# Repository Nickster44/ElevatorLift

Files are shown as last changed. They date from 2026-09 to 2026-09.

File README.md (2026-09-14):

# Elevator Lift Controller Redesign

This repository contains the Rev-A hardware design and inhibited software for a redesigned outdoor elevator lift controller. The original controller was a Particle Xenon sketch that drove an EM01 VFD over serial, watched a safety loop, counted position pulses in firmware, stored floor positions in EEPROM, and exchanged simple serial messages with a secondary relay/input board.

The new design goals are:

- Make motion control deterministic and auditable with an explicit state machine.
- Move encoder counting out of interrupt-heavy application code and into a quadrature counter IC.
- Store current position, floor targets, calibration values, faults, and event logs in nonvolatile MRAM.
- Host a local access-point web interface for setup, diagnostics, data logs, and maintenance actions, with optional station-mode connection to a local network.
- Keep safety functions electrically independent from the MCU wherever possible.
- Develop the custom controller board alongside a versioned firmware interface contract.

Important: this repository is not a certified elevator controller. The software here is a development baseline. Any real lift must use appropriately rated safety devices, hardwired interlocks, braking/enable circuits, limit switches, emergency stop hardware, enclosure design, and professional review before operation.

## Software Integration Status (2026-09-13)

The active software is a **buildable but hardware-inhibited N16R8 profile**.
GPIO35-37 are unavailable on this module. The 2026-09-13 hardware update moves
LIMIT_UP/LIMIT_DOWN/SERVICE_KEY to GPIO43/44/3 and makes GPIO42 a communications-only
UART enable, removing the MCU RUN and optional AUX circuits. Software contract v2
now adopts this revision. GPIO3 is input-only, UART0 application logging is disabled,
and UART1 supports STOP/monitor/readback while safety is open. RUN, drive writes,
motion and uploads remain inhibited. Stable input levels do not prove wire continuity.
No physical motion or hardware verification has been performed.

VFD communication now includes periodic STOP refresh (300 ms scheduled interval),
monitor/read traffic, and a separate bounded reply-retry policy. The drive's TIME
watchdog is read and reported, never automatically changed; communication failure
keeps STOP refresh active without restarting motion or clearing faults.

The manual-release STOP path is now target-bound: key/hold/direction release or
invalid direction/safety input queues STOP before ordinary work. Input intent is
reported separately from actual motion permission. The requested operational v3
profile, RF programming and calibration expansion are not complete; v2 remains inhibited.

See the [hardware change and routing handoff](docs/reviews/2026-09-13-pin-comms-fourlayer.md).
The PCB is synchronized and has four copper layers, but remains unrouted and
not layout-release/fabrication ready; isolation keepouts and fabricator-specific
stackup/USB geometry still need completion.

Start with the [software integration checklist](docs/software-integration-checklist.md),
[hardware-dependency handoff](docs/hardware-dependency-handoff.md),
[firmware guide](firmware/README.md) and [current API contract](webapp/docs/api-contract.md).
Portable motion/protocol/device logic has regression tests; target commissioning,
RF integration and several guarded API workflows remain incomplete. The WebUI
shows unavailable capabilities instead of simulating successful hardware actions.

## Current Repository Layout

Use the [documentation guide](docs/README.md) to distinguish current design
guidance from dated reviews and historical evidence.

```text
_old_resources/
  old_code.ino.txt                 Original Particle Xenon firmware
  EM01 Manual User_EN-V1.02.pdf     VFD manual; serial protocol starts on page 27
  SKF-Motor-Encoder-Unit---15276_1-EN.pdf
docs/
  hardware-requirements-matrix.md   Schematic-facing hardware requirements
  hardware-selection.md             Selected Rev-A hardware
  home-automation-integration.md    Local REST/Home Assistant/Google Home bridge plan
  jlcpcb-lcsc-sourcing.md           JLCPCB/LCSC-oriented major part matrix
  motion-control-and-calibration.md Motion strategy and measured stop calibration
  old-system-review.md              Existing firmware/hardware behavior and risks
  vfd-serial-protocol.md            Extracted EM01 serial protocol notes
  new-controller-requirements.md    Hardware and firmware requirements draft
  webui-vfd-and-storage-plan.md     WebUI, VFD parameter, and log storage plan
  webapp-embedded-delivery.md       ESP32 static bundle budget and serving rules
  field-verification-log.md         Observed legacy hardware and remaining site checks
  schematic-capture-readiness.md    Rev-A capture inputs, BOM register, and release gates
datasheets/
  README.md                         Local datasheet manifest for major ICs/modules
firmware/
  platformio.ini                    Inhibited N16R8 PlatformIO target
  include/
  src/
webapp/
  app/                              Full development and service-console UI
  embedded/                         Static entry point for the ESP32 build
  docs/                             WebUI API, safety, and delivery contracts
hardware/
  ElevatorLift.kicad_pro            KiCad 10 project; open this file
  ElevatorLift.kicad_sch            Root hierarchical schematic
  Power_RevA.kicad_sch              AC input and 12 V/5 V/3.3 V power
  MCU_Storage_RevA.kicad_sch        ESP32-S3, USB, MRAM and RTC
  VFD_Interface_RevA.kicad_sch      VFD UART and communications-only OE
  Encoder_Counter_RevA.kicad_sch    Encoder isolation and counter
  IO.kicad_sch                      RF, field inputs and outputs
  ElevatorLift.kicad_pcb            PCB WIP; full footprint/net transfer on a 90 mm x 90 mm outline with 86 mm hole centers
  ElevatorLift_Custom.kicad_sym     Project-owned symbols
  ElevatorLift_Custom.pretty/       Project-owned footprints
  SnapEDA-Library/                  Vendored imported symbols, footprints and STEP files
  sym-lib-table / fp-lib-table      Portable project library registrations
  architecture-blocks.md            Block-level hardware architecture notes
```

## Current Design Knowledge

The current hardware direction is an `ESP32-S3-WROOM-1U-N16R8` controller board in the VFD enclosure, using a self-hosted Wi-Fi AP as the primary service path and optional station Wi-Fi for local-network access. Ethernet is not a near-term requirement.

Known design constraints captured so far:

- KiCad 10.0.4 is the active hardware design version.
- Measured legacy mechanical target is approximately 90 mm x 90 mm with corner mounting-hole centers 86 mm apart; 2.56 mm hole diameter remains to be confirmed.
- The Rev-A VFD serial circuit has been cross-checked against the field design and reproduces its TI `TXS0104E` 3.3 V-to-5 V topology. The assembled board, connector pinout, reference, and idle levels still require bench verification before lift connection.
- The observed encoder path appears to be 12 V open-collector A/B with 270 ohm pullups and 270 ohm series resistors feeding a `TLP291-4` optocoupler. Trace details, current, and maximum pulse rate remain open.
- Legacy Linx/TE RXM-418-LR 418 MHz RF remote support is mandatory.
- Baseline control supply is RECOM `RAC10-12SK/277`, 12 V, 10 W, based on the previously observed installation; `C5199922` is a recorded sourcing reference, not verified current availability.
- Rev A retains a jumper-selectable external 12 V lighting input. Use it if measured controller margin is insufficient or future lighting requires more power than the onboard supply can provide.
- Critical state and recent logs should use 4 Mbit SPI/QPI MRAM, using the selected Siproin `PM004MNIATR`.
- Web assets, OTA staging and noncritical logs should use the module's 16 MB flash and 8 MB PSRAM first. Rev A does not include a separate QSPI NOR device.
- Outside control should use local REST first, optional MQTT later, and Home Assistant as the recommended bridge to Google Home, watches, and broader automation.
- Motion control should use measured deceleration-distance stopping, not PID. Planned calibration starts explicitly after valid floor programming and stores direction-specific offsets; target integration remains incomplete.

## Legacy Reference

The original pin map, behavior and risk analysis are retained in
[old-system-review.md](docs/old-system-review.md). They are historical evidence,
not wiring or operating instructions for Rev A.

## Firmware Direction

The firmware targets the exact N16R8 module using Arduino/PlatformIO and a versioned hardware interface contract. Portable core logic is tested separately from target adapters. A successful build is not permission to deploy.

Key modules:

- `core/Supervisor`: fault-latched motion, service, homing and measured calibration logic.
- `core/Em01`, `DriveScheduler`: framed/checksummed transactions, telemetry and readback.
- `core/Devices`, `Configuration`: LS7366R, PM004 MRAM, RTC and integrity-checked records.
- `core/Rf`: isolated learned-slot/epoch and input arbitration logic.
- `main.cpp`: inhibited target diagnostics, light output, networking and static hosting.
- `interface-contract.json`: confirmed pins and explicit unresolved hardware decisions.

## Local Web Interface/API

The firmware hosts static WebUI assets on port 80 and a fallback AP. Station credentials can be saved, but remote reboot is deliberately unsupported in the inhibited profile. Failed/lost station connectivity restores AP access. Blank API tokens disable writes.

Endpoints:

- `GET /` - embedded WebUI; no automatic demo mode.
- `GET /api/status` - versioned status, capabilities, blocked reasons and freshness.
- `GET /api/capabilities` - explicit supported capabilities.
- `GET /api/network` - current AP/station network status.
- `POST /api/network` - save station SSID/password and require a reboot.
- `POST /api/light` - idempotent light output command.
- `GET /api/logs/recent` - bounded durable MRAM events, unavailable on storage failure.
- `GET /api/vfd/parameters` - list documented VFD parameter metadata.
- `POST /api/move?floor=N` - strict input validation, then hardware-inhibited rejection.
- `POST /api/stop` - queues diagnostic STOP (202), or reports unavailable UART (503); neither transmission nor acknowledgement proves physical stopping.

Other commissioning, parameter-write, RF, restore and reboot endpoints are explicitly unsupported. See the API contract for remaining work; no UI capability implies hardware verification.

Fallback AP credentials are configured from `firmware/include/Secrets.h`, which is ignored by Git. Station network credentials are saved through the local web API.

Planned WebUI expansion includes local lift settings, RF pairing, VFD parameter read/write, current-limit/load-limit tuning, configuration backup/restore, and log export.

The preferred home-automation path is local REST API first, optional MQTT later, and Home Assistant as the bridge to Google Home. Google Home should not talk directly to the lift controller or bypass the controller's authentication, logging, and motion prechecks.

## Captured Hardware Architecture

The Rev-A design contains the following blocks; physical qualification remains open:

- Exact `ESP32-S3-WROOM-1U-N16R8` external-antenna Wi-Fi module.
- Fused 120 VAC + neutral input, isolated 12 V supply, 5 V rail, and 3.3 V rail.
- VFD UART interface reproducing the field-used 3.3 V-to-5 V `TXS0104E` topology, with an assembled-board bench gate before lift connection.
- LS7366R SPI quadrature counter.
- Encoder input conditioning for the observed 12 V open-collector quadrature outputs, including isolation/level translation before the counter.
- SPI MRAM for live position snapshots, settings, recent event logs, and fault records.
- The selected N16R8 module's 16 MB flash and 8 MB PSRAM serve WebUI assets, OTA staging and noncritical data; no separate Rev-A QSPI device is planned.
- Hardware safety chain independent of application firmware.
- External hardwired motion authority; GPIO42 enables UART translation only, not RUN or a brake.
- Protected digital inputs for call buttons, RF receiver, limit switches, home switch, and safety loop.
- Mandatory RXM-418-LR RF receiver path.
- Protected 12 V MOSFET light output with jumper-selectable onboard or external 12 V supply. AUX has been removed.
- Watchdog and brownout detection.
- Surge/ESD/EMI protection suitable for outdoor wiring and a VFD enclosure.

The service/recovery interface uses dry-contact inputs: J43 provides SERVICE
KEY, HOLD-TO-RUN and GND; J44 provides SERVICE UP, SERVICE DOWN and GND. The
intended external hardware is a maintained keyed service switch, a momentary
hold-to-run control, and momentary UP/DOWN controls. These optocoupler-conditioned, shared-ground
MCU inputs are authorization/command inputs only; they are not a safety-rated
enabling circuit and may not bypass the independent emergency-stop, final-limit,
watchdog or VFD motion-authority paths.

## Opening The Hardware Project On Another Computer

Clone or copy the complete repository and open `hardware/ElevatorLift.kicad_pro`
with KiCad 10. The custom and SnapEDA libraries are stored under `hardware/` and
registered through `${KIPRJMOD}` paths, so no `D:\Downloads` or user-profile
library path is required. Do not copy only the `.kicad_pro` file: the five child
schematics, board, project library tables, custom libraries and vendored
SnapEDA library directory must remain together.

## Physical Verification Checklist

The initial on-site observations are recorded in `docs/field-verification-log.md`.
Before hardware release, complete the remaining checks below. The
[external-box evidence checklist](docs/reviews/2026-09-13-manual-control-box.md)
defines the non-energized wiring review; this list does not authorize live testing.

1. Confirm the estimated 40 mm enclosure height and 12 mm underside clearance, then measure connector/wire-bend keepouts and airflow.
2. Confirm the approximately 90 mm x 90 mm board, 86 mm mounting-hole centers, 2.56 mm hole diameter, screw size, and standoff material.
3. Old controller hardware: photograph both sides of the Particle/Xenon board and accessory Nano board, record IC markings, regulator parts, RF receiver wiring, level-shifting parts, optocouplers, drivers, relay part numbers, fuses, MOVs, terminal blocks, and any bodge wiring.
4. VFD serial interface: verify the field-matched `TXS0104E` circuit on the assembled board, including header pinout, idle voltage, common/reference, polarity, receive level, cable length, and bench behavior.
5. Power input: where 120 VAC can be tapped, whether it is upstream/downstream of the disconnect, available neutral, protective earth/chassis connection, fuse location, wire gauge, and connector style.
6. Existing 12 V loads: light voltage/current, inrush behavior, shared return path, connector type, and whether any solenoid/interlock output still needs power.
7. Encoder wiring: verify the observed 12 V supply, 270 ohm pullups, 270 ohm series resistors, `TLP291-4` path, exact encoder model, A/B idle voltage, cable/shielding, connector pinout, and maximum pulse rate.
8. Button, home, limit, and safety wiring: voltage levels, normally-open/normally-closed behavior, whether contacts are dry or powered, cable routing, and what is hardwired versus MCU-only.
9. RF system: confirm receiver module marking, antenna type/location, data output idle level, remote count, remote mapping, pairing behavior, and the separate wired `LEARN` node.
10. Grounding and EMI: cabinet earth strategy, shield terminations, VFD motor lead routing, separation between mains/motor wiring and control wiring, and any existing noise filters.
11. VFD parameters: dump or photograph current drive parameters, especially acceleration, deceleration, max frequency, current/overload settings, serial timeout, and any stop/enable terminal configuration.
12. Safety devices: identify final limits, emergency stop, gate/latch devices, brakes, and any non-MCU circuits that remove motion authority.

## Remaining Software Work

Drivers, integrity-checked MRAM records, token authentication and host protocol
simulations exist. Track remaining operational motion, RF capture/programming,
explicit calibration, guarded settings and update workflows in the
[integration checklist](docs/software-integration-checklist.md).

## Build Firmware Without Deployment

Install PlatformIO, then run:

```powershell
cd firmware
pio run
```

Upload and uploadfs deliberately fail in this profile. See the
[firmware guide](firmware/README.md) for host tests and filesystem builds and the
[WebUI guide](webapp/README.md) for mocked browser tests. Do not remove the inhibit
to try hardware; physical qualification remains separate.

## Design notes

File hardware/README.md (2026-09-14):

# Hardware / KiCad Workspace

This folder is the hardware design workspace. The KiCad 10 project now contains a Rev-A schematic capture and an unrouted four-layer PCB for review. It is not yet approved for PCB layout or manufacturing.

## Files

| File | Purpose |
| --- | --- |
| `ElevatorLift.kicad_pro` | KiCad project |
| `ElevatorLift.kicad_sch` | Root hierarchical schematic |
| `Power_RevA.kicad_sch` | Fused AC input and isolated 12 V, 5 V and 3.3 V rails |
| `MCU_Storage_RevA.kicad_sch` | ESP32-S3, USB, MRAM, RTC and service interfaces |
| `VFD_Interface_RevA.kicad_sch` | 3.3 V/5 V UART translation; communications-only enable, no MCU RUN output |
| `Encoder_Counter_RevA.kicad_sch` | Isolated encoder inputs and LS7366R counter |
| `IO.kicad_sch` | Linx RF, monitored field inputs and light output; optional AUX removed |
| `ElevatorLift.kicad_pcb` | PCB work-in-progress: 90 mm x 90 mm outline, 86 mm corner-hole centers, and the complete schematic footprint/net transfer |
| `ElevatorLift_Custom.kicad_sym` / `ElevatorLift_Custom.pretty` | Project-owned custom symbols and corrected/provisional footprints |
| `SnapEDA-Library` | Repository-owned copy of imported symbols, footprints and supplied STEP files |
| `sym-lib-table` / `fp-lib-table` | Project library registrations using portable `${KIPRJMOD}` paths |
| `architecture-blocks.md` | Schematic page/block plan |

## Current Schematic Pages

1. Root hierarchy and design notes.
2. Power (`Power_RevA`).
3. MCU and storage (`MCU_Storage_RevA`).
4. VFD interface (`VFD_Interface_RevA`).
5. Encoder counter (`Encoder_Counter_RevA`).
6. Consolidated RF, field inputs and outputs (`IO`).

The superseded standalone RF, safety, output and connector child sheets were
removed after their contents were consolidated into the active Rev-A hierarchy.

## Rev-A Capture Assumptions

Use [the hardware requirements matrix](../docs/hardware-requirements-matrix.md) and the main README physical verification checklist as the source of truth. The current schematic assumptions are:

- Target PCB outline: 90 mm x 90 mm; corner mounting-hole centers 86 mm apart. The reported 12 mm underside and approximately 40 mm upper clearances are enclosure estimates, not defined keepout radii. Verify screw-head/standoff envelopes and the estimated 2.56 mm hole diameter before layout release.
- Main supply: fused 120 VAC + neutral to exact RECOM `RAC10-12SK/277`; protected 12 V distribution uses `MF-MSMF075/24X`; 5 V uses an `R-78E5.0-0.5`; and 3.3 V uses an AP63203 stage with Bourns `SRP7028A-2R2M`.
- 5 V source sharing: separate `LM66100DCKR` ideal diodes isolate the onboard 5 V converter and USB VBUS before they join the 5 V rail. USB VBUS alone does not power the separate 3.3 V regulator; an approved bench-power procedure remains necessary.
- VFD serial: the `TXS0104E` circuit matches the field design, with the `TSW-104-07-G-S` header ordered 5 V, GND, RX, TX. Assembled-board pinout and bench behavior remain release gates.
- Encoder: 12 V field inputs use 2.2 kOhm LED resistors into `TLP291-4` isolation. This intentionally replaces the observed legacy 270 ohm values to avoid excessive optocoupler current; verify reliable switching on the actual encoder.
- RF: RXM-418-LR and `LICAL-DEC-MS001` support is mandatory; include a separate wired `LEARN` interface plus a local service button/pads.
- Light output: protected 12 V MOSFET output with an onboard/external supply selector. The previous 750 mA lighting operated from the 10 W RAC10 supply; verify Rev-A load margin, and select the external 12 V lamp input if controller demand or upgraded lighting exceeds the onboard budget.
- Service station: J43 accepts dry-contact SERVICE KEY and HOLD-TO-RUN inputs with a shared GND; J44 accepts dry-contact SERVICE UP and SERVICE DOWN inputs with a shared GND. Use a maintained key switch and momentary controls. These are optocoupler-conditioned MCU inputs sharing controller GND, not an independent galvanic barrier or a safety-rated enabling circuit.
- Current MCU assignment: LIMIT_UP GPIO43/module pin 37 through 1k R62; LIMIT_DOWN GPIO44/pin 36; SERVICE_KEY GPIO3/pin 15. GPIO35/36/37 remain NC for octal PSRAM. J11 UART pins 3/4 are now NC; use native USB. Preserve active-low inputs and default JTAG eFuses; see the reset/boot details in the current handoff.
- GPIO42 is VFD_COMMS_ENABLE and connects only U24 OE plus R24's 10k pulldown. R25/U25/J25/TP26 and AUX R59/R60/Q41/F41/D42/J47 are removed. The separate external hardwired safety loop remains the required RUN authority, subject to VFD configuration verification.

## PCB Preparation Status

- The current board contains 126 footprints (including four mounting holes) and 140 nets. The 90 x 90 mm outline runs from `(97.26,52.29325)` to `(187.26,142.29325)` mm. The four provisional 2.6 mm NPTH holes retain 86 mm spacing and a 2 mm offset from each adjacent edge.
- Net classes retain 3.2 mm mains clearance and 0.8 mm SELV power track width (0.2 mm clearance), plus the provisional USB differential-pair settings.
- The downloaded ESP32 module footprint contained invalid 0.2 mm plated holes. `ElevatorLift_Custom:ESP32-S3-WROOM-1U-N16R8_CorrectedV2` replaces it with the correct perimeter geometry and nine symbol-compatible exposed-pad segments.
- The provisional mains connector is now Phoenix Contact `1717732`, 7.62 mm pitch. The former 5 mm-pitch part could not satisfy the selected 3.2 mm mains clearance rule.
- Existing footprint positions and sides are preserved except for a local C23/C26 move that shortens U20's input/bootstrap loops; new R62 was also placed. Four layers are enabled: F.Cu, In1.Cu (SELV GND reference), In2.Cu (power/constrained signals), B.Cu. No tracks or zones were created. The nominal 1.6 mm board thickness is not a selected fabricator stackup.
- Current verification: ERC 0 errors/31 unchanged warnings; PCB DRC 325 unrouted errors, 181 warnings, no other errors, zero schematic parity findings. The final Konnect synchronization dry run is a no-op. These checks do not make the board layout-ready.
- See [the current handoff](../docs/reviews/2026-09-13-pin-comms-fourlayer.md) for exact pin mapping, prototype gates, placement concerns, all-layer isolation/antenna keepouts still to implement, and the provisional USB rule. Konnect's `.konnect/project.json` records routing guidance, not enforced KiCad custom rules.

Dated review results are evidence, not a live release status. See the
[external-box review](../docs/reviews/2026-09-13-manual-control-box.md) for the
latest field-interface evidence and unresolved independent stopping authority.

## Portable Project Libraries

Open `ElevatorLift.kicad_pro`, not an individual child sheet. Both project
library tables use `${KIPRJMOD}` paths:

- `SnapEDA` resolves to `hardware/SnapEDA-Library`.
- `ElevatorLift_Custom` resolves to the custom symbol file and footprint folder
  beside the project.

The repository-owned SnapEDA directory is a byte-for-byte copy of the imported
download and includes the supplied STEP files. Standard KiCad libraries are
still required, so install KiCad 10 with its normal symbol and footprint
packages on the destination computer.

See [field observations](../docs/field-verification-log.md) and the
[capture register](../docs/schematic-capture-readiness.md) for the confirmed observations, reusable-parts register, and the remaining release gates.

## KiCad Tooling

This project is pinned to KiCad 10.0.4. Use `tools\kicad.ps1` rather than a
generic `kicad-cli` command so automated checks do not accidentally run against
the also-installed KiCad 8 version.

```powershell
# From the repository root
powershell -ExecutionPolicy Bypass -File hardware\tools\kicad.ps1 -Action Version
powershell -ExecutionPolicy Bypass -File hardware\tools\kicad.ps1 -Action Validate
powershell -ExecutionPolicy Bypass -File hardware\tools\kicad.ps1 -Action Gui
```

`Validate` writes KiCad-native ERC and DRC JSON reports to `hardware\reports`
by default. The reports are generated design-review artifacts and should be
regenerated whenever the schematic or board changes.

The helper scripts auto-detect conventional OneDrive/Documents KiCad plugin
locations. On a different layout, set `KONNECT_PLUGIN_ROOT` to the installed
Konnect directory and `KICAD_10_BIN` to the KiCad 10 `bin` directory. Neither
environment variable is required merely to open and edit the project in KiCad.
Use PowerShell 7 for the Konnect batch helper; the basic KiCad launcher also
supports Windows PowerShell 5.1.

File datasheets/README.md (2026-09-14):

# Datasheet Library

This folder holds local datasheet copies for the selected parts and historical alternatives. Treat these as design references, not as a released BOM. Before schematic release or JLCPCB assembly order, re-check the latest manufacturer revision, LCSC stock, JLC assembly support, package, and lifecycle status.

| File | Block | Part / family | Source URL |
| --- | --- | --- | --- |
| `ESP32-S3-WROOM-1_WROOM-1U_datasheet.pdf` | MCU / Wi-Fi | ESP32-S3-WROOM-1U-N16R8 | https://www.espressif.com/sites/default/files/documentation/esp32-s3-wroom-1_wroom-1u_datasheet_en.pdf |
| `LS7366R-S_quadrature_counter_datasheet.pdf` | Quadrature counter | LS7366R-S | https://lsicsi.com/wp-content/uploads/2021/06/LS7366R.pdf |
| `Siproin_PM004MNIATR_4Mbit_SPI_MRAM_datasheet.pdf` | Critical nonvolatile memory | PM004MNIATR | https://atta.szlcsc.com/upload/public/pdf/source/20260107/FA25787C4C17263044D220C5BFBDF06F.pdf |
| `Winbond_W25Q128JV_128Mbit_SPI_Flash_datasheet.pdf` | Deferred bulk-storage reference; not fitted in Rev A | W25Q128JVSIQ | https://datasheet.lcsc.com/datasheet/pdf/d009d960f1daec6149edaa35b7dae856.pdf?productCode=C97521 |
| `MicroCrystal_RV-3028-C7_RTC_datasheet.pdf` | RTC | RV-3028-C7-32.768kHz-1ppm-TA-QC | https://www.microcrystal.com/fileadmin/Media/Products/RTC/Datasheet/RV-3028-C7.pdf |
| `TI_ISO6721_dual_digital_isolator_datasheet.pdf` | Historical UART isolation; not fitted | ISO6721BDR | https://www.ti.com/lit/ds/symlink/iso6721.pdf |
| `Chipanalog_CA-IS372x_dual_digital_isolator_datasheet.pdf` | Historical UART alternate; not fitted | CA-IS3721 / CA-IS372x family | https://datasheet.lcsc.com/datasheet/pdf/604064461aa0c12ec9a7680be1fb8a63.pdf?productCode=C528650 |
| `TI_ISO1211_ISO1212_digital_input_receiver_datasheet.pdf` | Historical input receiver; not fitted | ISO1211DR / ISO1212 | https://www.ti.com/lit/ds/symlink/iso1211.pdf |
| `Linx_RXM-418-LR_receiver_datasheet.pdf` | Legacy RF receiver | RXM-418-LR | https://datasheet.lcsc.com/datasheet/pdf/35ec37f75e2d2c95669ebbe0ea837597.pdf?productCode=C6670221 |
| `Mornsun_LS05-13B05R3_ACDC_module_datasheet.pdf` | Historical AC/DC option; not fitted | LS05-13B05R3 series | https://fiduspower.com/media/downloadable/files/attachment//l/s/ls05-13bxxr3.pdf |
| `RECOM_RAC10-12SK277_ACDC_module_datasheet.pdf` | 120 VAC to 12 V supply | RAC10-12SK/277 | https://g.recomcdn.com/media/Datasheet/pdf/.fNZH1XvY/.t0407127c408a9a98940f/Datasheet-122/RAC10-K_277.pdf |
| `Diodes_AP63200_AP63203_buck_datasheet.pdf` | 3.3 V buck regulator | AP63203WU-7 | https://datasheet.lcsc.com/datasheet/pdf/94820cc9e44613233ddcc1a15801eca3.pdf?productCode=C2071868 |
| `TI_SN74LVC2G17_schmitt_buffer_datasheet.pdf` | Historical buffer option; captured part is 74HC14D | SN74LVC2G17DBVR | https://www.ti.com/lit/ds/symlink/sn74lvc2g17.pdf |
| `LiteOn_MOC3063S_optotriac_datasheet.pdf` | Historical AC-light option; not fitted | MOC3063S-TA1 | https://dfsimg1.hqewimg.com/group5/M00/17/1F/wKhk3WYsy4-ACPLCAAL-o50Ymog025.pdf |
| `Maxim_MAX3483_MAX3485_RS485_datasheet.pdf` | Historical RS-485 option; not fitted | MAX3485ESA+T | https://www.farnell.com/datasheets/2002060.pdf |
| `TI_TXS0104E_level_translator_datasheet.pdf` | Observed VFD serial level translation | TXS0104E | https://www.ti.com/lit/ds/symlink/txs0104e.pdf |
| `RECOM_R-78E5.0-0.5_5V_regulator_datasheet.pdf` | Selected Rev-A 12 V to 5 V regulator; legacy board used it from 24 V | R-78E5.0-0.5 | https://recom-power.com/pdf/Innoline/R-78E-0.5.pdf |
| `Toshiba_TLP291-4_photocoupler_datasheet.pdf` | Observed encoder isolation | TLP291-4 | https://toshiba.semicon-storage.com/info/TLP291-4_datasheet_en_20191129.pdf?did=12858&prodName=TLP291-4 (local download pending) |
| `Linx_LICAL-DEC-MS001_decoder_datasheet.pdf` | Legacy RF decoder | LICAL-DEC-MS001 | https://www.te.com/en/product-LICAL-DEC-MS001.html (local download pending) |

## Scope and missing references

The selected parts are listed in [hardware selection](../docs/hardware-selection.md).
Historical PDFs remain available for traceability, but they are not approved
substitutions or evidence of current stock/pricing. No stock or price claim is
maintained in this manifest.

The TLP291-4 and LICAL-DEC-MS001 rows marked pending are source references, not
claims that those local files exist. The
[external-box review](../docs/reviews/2026-09-13-manual-control-box.md) cites the
Linx-authored decoder guide used for its baud table. Verify manufacturer revision,
exact package and installed hardware independently of a download or import.

The captured UART uses TXS0104E. The captured power supply is RAC10-12SK/277;
the 5 V AC/DC alternatives do not apply to the present board.

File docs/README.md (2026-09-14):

# Documentation Guide

Use current guidance for design work; dated review reports retain evidence and
must not be treated as a live pin map, BOM or readiness approval.

## Current design and implementation

- [Repository overview](../README.md) and [hardware workspace](../hardware/README.md).
- [Requirements](new-controller-requirements.md) and
  [hardware requirements matrix](hardware-requirements-matrix.md): intended capabilities.
- [Hardware selection](hardware-selection.md) and
  [capture register](schematic-capture-readiness.md): selected, captured blocks.
- [Hardware dependencies](hardware-dependency-handoff.md): unresolved qualification gates.
- [Software checklist](software-integration-checklist.md),
  [firmware guide](../firmware/README.md) and [API contract](../webapp/docs/api-contract.md):
  actual software support and remaining integration work.
- [Library requests](component-library-request.md),
  [sourcing references](jlcpcb-lcsc-sourcing.md), and
  [library portability](snapeda-library-import.md).

## Evidence retained deliberately

- [Field observations](field-verification-log.md) distinguish old-board observations
  from decisions for the new controller.
- [External manual-control box review](reviews/2026-09-13-manual-control-box.md)
  contains the missing wiring/brake evidence checklist. Its dated software snapshot
  is superseded by the current handoff, not its unresolved physical questions.
- [Pin/comms/four-layer report](reviews/2026-09-13-pin-comms-fourlayer.md)
  records the hardware change and connectivity checks; firmware subsequently adopted it.
- [Original integration review](reviews/2026-09-10-integration/README.md) and
  [old-system review](old-system-review.md) are historical, not current implementation.

Do not delete an unresolved safety or mechanical question merely because it is
old. Close it only with evidence. Component candidates and duplicate planning
text no longer applicable to Rev A have been removed from the current guides;
previous versions remain recoverable through Git history.

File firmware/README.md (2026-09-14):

# Controller Software

**Buildable, hardware-inhibited development profile. Not deployable. No uploads.**

The current profile targets ESP32-S3-WROOM-1U-N16R8: 16 MB QIO flash, 8 MB octal
PSRAM and native USB CDC. `interface-contract.json` is the versioned wiring
contract; `include/PinMap.h` is generated, not independently edited. The netlist
contract test checks confirmed assignments against the supplied review export.
Contract v2 adopts the 2026-09-13 finalized mapping: limits GPIO43/44, key GPIO3,
communications-only OE GPIO42. GPIO35-37 have no usable definitions. AUX is removed.
UART0 debug/IDF logging is disabled and UART0 detached before configuring input pins;
native USB remains the application console. ROM/bootloader output predates setup
and cannot be suppressed by this application; R62 and boot-waveform testing remain gates.
GPIO42 starts LOW, then enables only the TXS0104E after UART1 initialization.
Only STOP, monitor and parameter READ commands are target-bound; no RUN or WRITE.

Upper/lower-limit and service-key active-low readings require 100 ms stability with sample gaps <=25 ms. A transition,
invalid level or missing sample invalidates readiness immediately. Pulled-up single
inputs cannot distinguish open contacts from broken wires/absent field power.
`FieldContinuityQualified=false` therefore keeps input qualification false, in
addition to the unchanged global motion/upload inhibit. No setting or web override
can remove either gate. The external hardwired safety loop is the required independent motion authority;
its installed topology and drive/brake behavior remain unverified.

## Implementation Boundaries

Manual switch release now requests EM01 STOP independently of motion readiness.
`ManualStop.h` samples raw active-low key/hold/direction/SAFETY_MON before UART,
HTTP, SPI and persistence work each loop. Key/hold release, direction loss/change,
both directions, safety loss, invalid input or a sampling gap requests STOP without
waiting for the 100 ms qualification filter. Repeated pending STOP requests coalesce
so bounded protocol retries still expire. UART transmission remains subject to TX
buffer availability; this is not a verified real-time or physical-stop guarantee.
Key takeover requests STOP and rejects WebUI floor calls. Manual RUN remains inhibited.

The isolated normal RF map is D0 floor 1, D1 light toggle, D2 floor 3, D3 floor 2,
D4 STOP. Diagnostic baud defaults to 9600 and is configurable in the model; the
decoder jumper configuration must match this UART rate, not remote RF timing.
Target RF capture/programming movement and the operational v3 profile remain incomplete.

| Layer | Implementation | Boundary |
| --- | --- | --- |
| `core/Supervisor.*` | Unknown startup, three floors, top HOME edge, measured stop, fault latch, service release, limits/progress/overshoot, guards | Host simulation; thresholds uncommissioned |
| `core/Em01.*`, `DiagnosticVfd.h` | UART1 diagnostic STOP, monitor and readback, bounded retries/freshness | No RUN/WRITE; `DriveScheduler` remains isolated; late same-type reply ambiguity requires bench review |
| `core/FieldInputs.h` | Debounced active-low electrical readings, freshness and separate continuity qualification | No continuity/power-loss claim; target qualification remains false |
| `core/Devices.*` | LS7366R mode/readback and wrap tracking; PM004 word-address SPI; RTC coherent UNIX read; CRC journals | Target adapters build; no physical verification |
| `core/Configuration.*` | Versioned settings/floors/names/calibration/epoch serialization | Read on target; commissioning/write workflow not exposed |
| `core/ControllerSession.h`, `SafetyLedger.h` | Durable motion-intent/fault barriers, configuration, homing/program exit and calibration coordination | Host integrated; operational target binding pending |
| `core/ParameterJobs.h` | Guarded serialized jobs, readback/cache persistence, calibration invalidation | Isolated; no target UART binding |
| `core/Rf.h` | Release-to-rearm, slot/epoch association, five-command mapping, learn/erase confirmation models | Capture UART, qualified timing and persistent registry still to integrate |
| `main.cpp` | Inhibited diagnostics, real counter/storage/RTC adapters, light set-state, AP/station, bounded HTTP, LittleFS | No motion, homing, RF learning, settings writes, parameter writes, reboot or OTA |

The isolated session still starts single-record calibration on program exit.
Explicit WebUI start and direction-specific records are pending; see
[motion requirements](../docs/motion-control-and-calibration.md).

Diagnostic traffic uses 100 ms slots with periodic STOP refresh due every 300 ms,
interleaving monitor/read transactions and reading TIME first. Parameter 13 is skipped
because readback is unresolved. Reads use raw protocol units and
timestamped cache values, not persisted commissioning settings. Three failed attempts
poison the session until reset; STOP-only refresh continues, automatic reconnect is not.
API STOP returns queued status, never a stopped claim. Telemetry requires a validated
monitor younger than 500 ms; `monitorStopped` is only drive evidence, not physical
stopping. Public `stoppedConfirmed` remains false in this unqualified profile.

`VfdTiming.h` separates periodic refresh from 150 ms reply retries and the drive's
TIME watchdog. Read-back watchdog state is exposed/logged as unknown, disabled,
too-short, outside-policy or within-software-policy, never as physical qualification.
The isolated installer write workflow now permits TIME=0010 only (1 second);
shorter settings conflict with the retry/refresh margin. No drive setting is written
automatically and no target parameter-write/RUN capability has been enabled.

## Build And Test

From repository root:

```powershell
node firmware/scripts/generate-contract.mjs --check
node firmware/tests/contract.mjs
./firmware/tests/run.ps1
python firmware/tests/test_build_guard.py
```

From `firmware`: `pio run`. The environment name is retained for existing tooling;
the board definition is `boards/elevator-n16r8.json`, not the N8 devkit definition.
PlatformIO upload/uploadfs targets deliberately fail. Do not remove that gate to
try hardware. See [hardware dependencies](../docs/hardware-dependency-handoff.md).

From `webapp`: `npm ci`, `npm run build:embedded`, then
`node scripts/stage-firmware.mjs`. From `firmware`, `pio run -t buildfs` builds the
filesystem image without uploading. Full update constraints are in
[delivery notes](../webapp/docs/embedded-delivery.md).

## Network And Authentication

Configure unique AP credentials and a random API token of at least 16 characters
in ignored `include/Secrets.h`. A blank/short token **disables all writes**.
Only the `X-Lift-Api-Token` header is accepted; never a URL query token. The UI
holds the entered token in memory, not persistent browser storage. There is no
TLS on the embedded listener: use a trusted, isolated LAN/AP and an authenticated
local hub; do not expose this API to the Internet.

The AP starts for setup, closes after station connection and returns within the
5-second network check interval on loss. Saving network credentials writes NVS
without reconnecting or restarting. Restart is explicitly required; remote reboot
is disabled in this profile. Credentials are never returned by the API.

## Storage

PM004MNIATR: 524,288 bytes; two-byte aligned accesses and 18-bit **word** addresses.
Startup verifies manufacturer bytes and mode registers; unknown latency or
protection is rejected, not reset blindly. Writes issue WREN, WRITE, WRDI, READ
and compare. No SPI-flash erase/page-program assumptions are used.

- Bytes 0-1151: two historical position/state records, saved once per second.
- Bytes 2048-3199: two configuration records.
- Bytes 4096-5247: two safety-ledger records (latched fault / unfinished motion).
- Bytes 6144-7295: reserved for two parameter-cache records; not target-bound.
- Bytes 8192-450559: 768 durable event slots, 576 bytes each, up to 544 payload bytes.
- Remaining capacity reserved; configurable retention and denser binary event format remain open.

Records use explicit little-endian fields, schema version, length, sequence,
CRC32 and a last-written commit marker. A torn new record cannot replace the
previous committed record. The safety ledger records fault transitions immediately;
its portable motion-intent barrier must be committed before any future RUN.
Fault snapshots also latch a prior-boot fault, but position
snapshots never establish incremental encoder continuity. Boot requires homing
before any future normal motion. RTC time is nullable; no NTP/build-time clock is
fabricated. RTC setting/backup configuration is not implemented.

See [software checklist](../docs/software-integration-checklist.md) for current
verification and the remaining integration work. Passing host tests is not lift
qualification or proof of hard-real-time behavior.

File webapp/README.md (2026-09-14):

# Elevator Lift Web Console

The WebUI is a same-origin client of the versioned controller API. It starts
disconnected, never switches to demo mode, and never manufactures motion,
calibration, telemetry, pairing, logging or command success. Unsupported hardware
paths are visibly unavailable. A valid HTTP status response is not motion permission.

`lib/controller.ts` validates runtime status shape, versions, counts, capabilities,
freshness and contradictory permission fields. Encoder counts are decimal strings
to preserve signed 64-bit values. The server owns floor identity and position.
STOP always attempts a real request, even when status is disconnected; failure
is shown and never changes the displayed motion state to idle.

Hardware contract v2 adopts the 2026-09-13 handoff. Stable active-low input readings
are displayed separately from field qualification (still false). Diagnostic UART
STOP/monitor/readback is supported while safety is open; no RUN or write capability
is enabled. Queued STOP and acknowledgement never imply physical stopping.

## Development

Node 22.13+ and npm:

```powershell
npm ci
npm run check
npm run lint
npm test
npm run build:embedded
```

`npm run dev` starts the full development app. For the exact embedded entry:
`npm exec vite -- --config vite.embedded.config.ts --host 127.0.0.1 --port 5178 --strictPort`.
Without an API, the page remains disconnected with commands unavailable; it is
not a simulator. No server connects to physical lift hardware during tests.

## Reproducible Browser Test

From a clean checkout at repository root, with Node 22.13+ and npm installed:

```powershell
cd webapp
npm ci
npx playwright install --with-deps chromium
npm run test:browser
```

The install command downloads the browser matching the locked Playwright version;
on Ubuntu it also installs OS dependencies (sudo privileges may be required).
The runner builds the embedded bundle, starts Vite preview only on
`http://127.0.0.1:5178`, waits for readiness, runs the test, and closes its server
on success, failure, or interruption. Port conflicts fail instead of reusing an
unknown server; stop any existing preview on 5178 first. The run has a 120-second
deadline after the build. No module, browser-channel or target-URL overrides are used.

`tests/browser.mjs` retains desktop/mobile disconnect, real STOP transport with
failure reporting, malformed-status rejection, reconnection, and view overflow
assertions. All controller API requests are mocked: this is browser evidence,
not target or motion verification. Screenshots go to ignored `test-results/`.
CI runs this command after the WebUI build; `npm test` remains the separate
unit/SSR suite. Neither command deploys or contacts a physical controller.

## Embedded Delivery

`build:embedded` emits static files plus gzip variants. On 2026-09-13 the bundle
measured 237,468 raw bytes / 71,835 gzip bytes. `node scripts/stage-firmware.mjs`
copies the assets and a hash manifest into ignored `firmware/data`. Then
`pio run -t buildfs` builds the LittleFS image. No deployment/upload is authorized.

See [API](docs/api-contract.md), [remaining integration work](docs/firmware-integration-gaps.md)
and [delivery constraints](docs/embedded-delivery.md). The current UI deliberately
does not enable unimplemented setup, drive-write, RF or restore workflows.

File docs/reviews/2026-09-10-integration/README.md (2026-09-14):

# ElevatorLift end-to-end integration review

Review date: 2026-09-10. Baseline: `1c37a65` on `main`; see [source manifest](source-manifest.json) for the full commit and source hashes. This review concerns the saved repository design, not unrecorded changes in an open editor or an installed legacy controller.

## Historical scope

This baseline is superseded for current implementation status. Retained findings
and evidence remain useful for traceability; use the
[current dependency handoff](../../hardware-dependency-handoff.md) and
[software checklist](../../software-integration-checklist.md) for open work.
Do not apply its old GPIO map or missing-driver descriptions to current firmware.

## Assessment

**The pieces do not yet implement one operational controller.** They share a recognizable intended architecture, but the schematic describes a substantially more advanced controller than the firmware implements. The web application is a mixed live client and demonstration interface. The PCB is not fully routed.

- **Works together in offline tests:** firmware status JSON can be consumed by the actual web page handler; basic move/stop route names and token-header convention agree; EM01 transmit frames match manual examples; some provisional safety/limit checks, stop timeout, authentication, and NVS CRC checks execute successfully in host simulation.
- **Ready for limited development/bench work:** reproducible firmware builds, web builds, deterministic software simulations, and individual low-voltage peripheral characterization with motion outputs physically disconnected. A suitable development board and simulated UART/inputs can support firmware development. This does **not** mean the current custom PCB or complete application is ready to connect to a drive.
- **Prevents complete operation:** N16R8-reserved GPIOs used for limits/service; extensive firmware GPIO mismatch including reversed VFD UART; unimplemented enable control; coupled serial-enable/run-permit circuit; no LS7366R/MRAM/RTC drivers; missing valid-position/homing/calibration/service states; unsafe STOP/fault/freshness behavior; unsupported web operations and misleading live/preview transitions; missing embedded web delivery; unfinished PCB and independent safety/installation verification.

No new-controller function was demonstrated on powered hardware or verified end to end during this review. Historical field observations establish requirements and legacy behavior, not Rev-A validation. No mains was energized, no firmware uploaded, no drive connected, and no physical command sent. Production sources, library tables, schematics, PCB, firmware and UI were preserved. Only this review directory was added; nothing was committed or pushed.

## Evidence and methods

| Evidence | Result and limit |
| --- | --- |
| `pio run` in `firmware` | PASS. Espressif32 7.0.1, Arduino-ESP32 2.0.17, GCC 8.4.0. RAM 48,744/327,680 bytes; application 790,257/3,342,336 bytes. Built the configured **N8/no-PSRAM development target**, not a qualified N16R8 board target. |
| `npm run check` | PASS, TypeScript. Type correctness is not runtime response validation. |
| `npm run build:embedded` | PASS. 246,798 raw bytes / 73,849 gzip bytes across HTML/CSS/JS. Assets are generated, not integrated into firmware. |
| `npm test` | PASS: one server-rendered HTML smoke test. It does not call firmware or exercise controls. |
| `npm run lint` | PASS. No functional/safety assurance implied. |
| [Host C++ checks](host-results.txt), [runner](run-host.ps1), [source](host/review.cpp) | **37 observations confirmed**, including intentionally reproduced defects. Compiles the actual unmodified `main.cpp` and production support `.cpp` files against review-only Arduino/GPIO/Serial/HTTP/Wi-Fi/Preferences substitutes. No physical transports. Passing reproduction checks means the reported defect exists, not that safety requirements pass. |
| [Web handler checks](web-results.json), [runner](check-web.mjs) | **8 observations confirmed** using the actual transpiled `page.tsx`, fake hooks/JSX/fetch/timers, and JSON emitted by the actual firmware serializer. This is handler simulation, not browser DOM, real React scheduling, HTTP transport, Wi-Fi or electrical validation. |
| [Konnect results](konnect-results.json), [collector](collect-kicad.ps1) | All six saved sheets inspected; full review `status=complete`, no coverage diagnostics, 229 resolved symbols, zero unresolved. Board coverage 135 footprints, 496 pads, 144 named nets. Complete tool coverage is **not** complete electrical qualification. |
| [Exported netlist](current.net), [readable export](netlist-summary.json) | Fresh KiCad 10.0.4 export through Konnect. Hardware paths below derive from this export, not prior readiness claims. [Parser](inspect-netlist.mjs) reads exported data only. |
| [ERC](erc.json) | 0 errors, 31 warnings: 14 footprint-link diagnostics, 9 off-grid endpoints, 6 same local/global labels, 2 U11 pin-type notices. No new duplicate-power-reference or U30 multi-unit-value error reproduced. |
| [DRC](drc.json) | **343 unconnected items**, 191 other warnings; schematic parity list empty. Of the 191: 113 footprint-library differences, 14 missing-library diagnostics, 26 silk-over-copper, 26 silk-overlap, 12 silk-edge-clearance. NOT READY for fabrication. |
| Structural checks | Zero label-short/orphan findings on each sheet. Sheet-local single-pin counts 0/2/22/2/4/17 are mostly cross-sheet labels; full-hierarchy export has no unexpected single-node net (remaining single-node entries explicitly marked no-connect). Do not mistake sheet-local warnings for disconnected hierarchy nets. |
| Additional audits | Six sheet-local bulk-capacitance warnings and U40/U24 proximity warning. Shared-rail bulk exists (e.g. C20, C22, C24/C25, C15); audit warnings are not proof those rails lack bulk. Physical decoupling quality still depends on layout. |
| [Library resolution](library-resolution.json) | Konnect resolves project-local decoder symbol, corrected ESP32 footprint and USB footprint. Current ESP footprint has 49 pads (including nine ground segments); queried ESP/USB footprints have no linked 3D model. This does not validate every pad/mechanical dimension or prove another computer opens the project. |

The initial PDF extraction failed on console encoding and succeeded using UTF-8. The original EM01 manual pages 27–30 were read; parameter/example tables on pages 29–30 were also rendered and visually checked. Tool-discovery output parsing needed one correction; final Konnect checks completed. No build prerequisite remained missing. Physical, real-browser/live-server, brownout, RTOS timing and manufacturing qualification checks remain unperformed, as detailed below.

### Reproduce the offline checks

From repository root:

```powershell
# Requires existing local PlatformIO/toolchains and webapp npm dependencies.
Push-Location firmware
pio run
Pop-Location
Push-Location webapp
npm run check
npm run build:embedded
npm test
npm run lint
Pop-Location
& docs/reviews/2026-09-10-integration/run-host.ps1
node docs/reviews/2026-09-10-integration/check-web.mjs
```

`run-host.ps1` currently names the installed MSYS2 compiler path and writes its executable to the Windows temporary directory. Test secrets are fabricated in `host/Secrets.h`; no real credentials are needed. `collect-kicad.ps1` requires PowerShell 7 and the installed Konnect plugin and refreshes generated review evidence. [Build logs](build-results.json) were captured by [check-builds.ps1](check-builds.ps1). Host Preferences models success/failure/corruption, not ESP flash timing, wear, atomicity or Xtensa struct layout. Network substitutes do not simulate the production HTTP parser's blocking behavior.

## Intended system and functionality/continuity matrix

Requirements are synthesized from `README.md`, `docs/new-controller-requirements.md`, `docs/hardware-requirements-matrix.md`, `docs/motion-control-and-calibration.md`, `docs/field-verification-log.md`, hardware capture documents, and prior selections: **three landings**, existing five-button 418 MHz remotes (no new transmitter/encoder on this board), N16R8, top HOME near floor 3, LS7366R, PM004MNIATR, native USB, RAC10-12SK/277 and 12 V lamps, J43/J44 local service controls. Auxiliary output is provisioned; interlock/solenoid outputs and external asset flash/SD are not mandatory Rev-A functions. MQTT is optional, Ethernet deferred.

Completion vocabulary: **Planned** = requirement only; **Partial** = missing functional layers; **Implemented/untested** = code/circuit exists without applicable verification; **Automated subset** = stated behavior tested in simulation/build only; **Bench-tested** and **End-to-end verified** require physical evidence. No row qualifies for the latter two for this new design. “Captured” means schematic connectivity, not assembled hardware.

Source shorthand: **FW** `firmware/src/main.cpp`; **Pins** `firmware/include/PinMap.h`; **UI** `webapp/app/page.tsx`; **NET** fresh exported netlist above. Mismatch IDs link conceptually to the next section.

| Requirement | Physical/circuit-to-firmware path | API/UI/output or feedback | Current completion and evidence | Remaining gap |
| --- | --- | --- | --- | --- |
| PWR-001/002: 120 VAC to isolated 12 V | J20 L → F20/MOV → PS20 RAC10; PS20.5 → F21 → +12V; PS20.4 → R21 → GND | No rail-health telemetry | Captured/untested, NET Power | M05/M25: load/fuse/thermal and mains review; PCB routing |
| PWR-003/004: 5 V and 3.3 V | +12V → PS21/U21 → +5V; +12V → U20/L20 → +3V3 | MCU/peripheral supply | Captured/untested, NET | No full load/startup/source-change measurement |
| MCU-002: USB programming and recovery | J10 D−/D+ → U10 GPIO19/20, U12 protection; J11 UART0 and BOOT/EN | Build serial behavior/ROM recovery | Partial; data nets present | M04/M05: correct target, USB-only power missing, runtime CDC/upload verification |
| MCU-001: N16R8 controller | U10 exact module/CorrectedV2 footprint | All controller services | Partial; build passes a different memory configuration | M01–M04: reconcile actual GPIO availability and build profile |
| Three landing calls, signed upward-positive position | RF or HTTP → `requestMoveToFloor()` → target/count comparison → UART | `/api/move`, `/api/status`; three UI buttons | Partial; host accepts calls with provisional inputs | M02/M06/M07: hardware counter absent in software, four hardcoded firmware floors, no valid-position gate |
| RF-001: existing five-button remotes | J40 → U40 RXM-418-LR → U41 decoder → GPIO4–8 | FW button handler; UI imitation of layout | Partial; data nets match five GPIO numbers | M08: floor mapping is 3/4/STOP/2/STOP, no light/floor1; no source-aware arbitration |
| ENC-001/002: encoder conditioning | J30/J31 open-collector A/B → R30/31 2.2k → U30 → R32/33 10k → U31 Schmitt → U32 A/B | Intended counter-derived status | Captured/untested | M06/M24: no SPI driver; confirm current, direction, rate, missing-pulse/noise behavior |
| ENC-003: hardware quadrature counting | U32 4 MHz clock, 3.3 V, SPI shared with U11 | Intended 32-bit counter extended to signed system coordinate | Planned software; FW currently two increment/decrement ISRs | M06: configure registers/count width/filter, rollover and reset synchronization |
| ENC-004: top HOME/reference | J41.2 → U42B → HOME → U10 GPIO2 | FW reads GPIO10 and zeroes position while idle | Partial/incompatible | M02/M07: HOME origin conflicts with floor table; no seek/backoff/reference validation |
| Program floor positions | Counter/local controls → intended configuration records | UI Setup edits local component state only | Planned controller support | M07/M16: no `/api/floors`, persistence, range/order/tolerance or explicit position-valid state |
| Measured stopping-distance calibration | Counter + drive ramp → measured coast distance | Drive panel reports sample “current” calibration | Planned, not measured | M09/M16: no state machine/measurement/storage/invalidation; fake UI qualification |
| Predictive normal stopping | `remaining <= activeCommand.stopOffsetCounts` → STOP | stopping/idle status | Partial; threshold and timeout simulated | M09/M10: constant threshold ignores saved setting, overshoot, physical stopped verification |
| Safety loop monitor | J41.1 → U42A → GPIO1 active LOW healthy | FW GPIO9 → `safetyOk`; UI banner | Partial; provisional-input safety rejection tested | M02/M11/M15: actual safety wire not read; banner not full motion permission |
| Final upper/lower limits | J42 → U42C/D → GPIO35/36 | FW GPIO11/12; UI limit pills | Partial/incompatible | M01/M02: reserved GPIOs and wrong software map; external hardwired final-limit chain unverified |
| Independent motion authority/E-stop | Intended external chain; U25/J25 open collector under GPIO42 | No enable/watchdog driver | Planned safety integration; output captured | M03/M11: external circuit/terminal semantics missing; serial STOP alone insufficient |
| MCU reset/watchdog/power loss safe state | R24 pull-down, output gate pull-downs, reset network | Startup writes VFD settings; no safe shutdown sequence | Partial; problematic boot/reboot simulated | M10/M11/M20: no qualified watchdog path or restart permission policy |
| Sensor/VFD fault detection and latching | Inputs + counter + UART replies | FW Fault/lastFault | Partial; some faults and timeout tested | M10/M11: absent progress/idle-motion/VFD health checks; STOP clears latch |
| IN-003: keyed service recovery | J43 key/hold, J44 up/down → U43 → GPIO37–40 | UI service toggle local only; recovery panel locked | Planned software | M01/M12: no local-authority state/jog/deadman/timeout/channel selection or logs |
| VFD-001: EM019600 8N1 | U10 → U24 TXS0104E → J24 5V/GND/VFD RX/VFD TX | `VfdProtocol` TX + weak STOP ACK handler | Partial; transmit vectors automated | M02/M03/M10: GPIO swap, OE low, no robust parser/transaction freshness |
| VFD telemetry/alarm reporting | MONITOR frame → intended cached telemetry | UI fixed 0Hz/0A/326V/34°C and “Communicating” | Planned receive implementation | M10/M15: monitor not polled/parsed, faults cannot remove permission |
| VFD-003: parameter access | HTTP handlers send get/set commands | Metadata routes exist; Drive panel not connected | Partial; ranges/idle-write rejection subset tested | M13/M16: wraparound, no readback/completion, access labels unenforced, parameter13 ambiguity |
| RF-002: learn/cancel/erase | GPIO14 → D40 → U41.11 plus SW40; MODE_IND GPIO16 | Browser timers only | Captured hardware/planned firmware | M17: no GPIO driver/API, deliberate learn pulse vs erase hold, reset cancellation |
| RF-003: transmitter identity/names | U41.9 TX_ID → GPIO15 | Browser sample remote IDs | Planned | M17/M18: actual ID is reusable learned slot, capture/association/registry and reset reconciliation missing |
| OUT-001: light toggle | GPIO41 → R57/Q40 → J46; JP40 onboard/external supply | UI `/api/light/toggle`; FW no route | Partial circuit only | M16/M25: implement state, repeated-command semantics, load characterization |
| Optional auxiliary output | GPIO3 → R59/Q41 → J47 | No firmware/API | Captured, optional planned feature | Define intended use or declare unavailable; evaluate boot strap/output defaults |
| MEM-001/005: critical position/calibration/settings | U11 PM004MNIATR on SPI | `PositionStore`/`LiftSettingsStore` use ESP NVS | Partial substitutes; CRC round-trip/corruption simulated | M06/M19: no MRAM driver/schema/sequence/redundancy/validity or calibration record |
| MEM-004: offline time | U13 RV3028, J12 backup, GPIO47/48 I²C | Events use `millis()` | Captured/planned software | M02/M19: GPIO48 misused as LED, no RTC driver/backup qualification/time validity |
| Logs and retention/export | Intended MRAM+RTC+source-aware events | `/api/logs/recent` RAM32; UI hardcoded events/CSV button | Partial | M19/M16: persistent log/2048 setting/accepted-rejected reason/source/time and UI consumption absent |
| NET-001/002: AP/STA recovery | ESP Wi-Fi → setup/reconnect/AP logic | Network GET/POST; UI editor stub | Implemented/untested on hardware; compiles | M20: fallback behavior, credential validity, JSON escaping, slow client responsiveness |
| Local REST/auth/automation | `ApiAuth` header token, optional arg token | UI localStorage token, status/move/stop | Partial; configured-auth rejection and status data compatibility automated | M13/M14/M20: auth optional by default, no role/origin policy, no MQTT, weak validation/error detail |
| MEM-002: self-hosted WebUI/updates | Module flash and intended LittleFS/OTA | Embedded bundle builds separately | Partial build tooling only | M04/M21: root serves diagnostic HTML, no static file serving/filesystem image or OTA workflow |
| Backup/restore/versioning | Intended versioned settings/calibration/remote registry | UI success-like toast but no file or endpoint | Planned | M18/M19/M16: transaction/migration/reconciliation not implemented |
| UI freshness/permission/error recovery | HTTP status → page state → operator decisions | Three-second polling, catch switches demo on | Partial, defects reproduced | M14/M15: no schema/capabilities/timeouts, false online/idle/telemetry, discarded error reasons |
| MECH/EMI/portability | 90mm class outline/86mm hole centers, separate RF/Wi-Fi antenna paths, local libraries | Same saved project on another machine | Partial; hierarchy/libs resolve; DRC incomplete | M22/M23/M25: routing, qualified footprints, clearance/earth/enclosure and clean-clone validation |

## Interface mismatches and practical impact

### M01 — N16R8-reserved pins assigned to operational inputs — blocker

`hardware/MCU_Storage_RevA.kicad_sch`, U10 physical pin **28/IO35 = LIMIT_UP**, **29/IO36 = LIMIT_DOWN**, **30/IO37 = SERVICE_KEY**. Espressif identifies IO35–37 as unavailable for other uses on the octal-PSRAM variant. These cannot be treated as ordinary GPIO on the selected N16R8. Firmware also configures IO35/36 as interrupt inputs. A symbol with these pins drawn as ordinary bidirectional pins and an ERC pass do not make that mapping valid. Reallocate these functions, then establish one versioned hardware/software pin contract; do not “solve” it merely by enabling PSRAM in the build. [Espressif module datasheet, section 3 notes](https://www.espressif.com/sites/default/files/documentation/esp32-s3-wroom-1_wroom-1u_datasheet_en.pdf).

### M02 — GPIO and peripheral roles disagree — blocker

All U10 pin numbers below are module/symbol pins, not GPIO numbers. Firmware evidence: `firmware/include/PinMap.h:7` and FW `setupPins():709`, UART initialization `:734`.

| Intended net/function | U10 pin / GPIO from NET | Firmware actually assumes | Impact |
| --- | --- | --- | --- |
| Safety LOW=healthy | 39 / GPIO1 `SAFETY_MON` | GPIO9 | Reads MRAM chip-select net as safety instead of U42 safety output. |
| HOME LOW=active | 38 / GPIO2 `HOME` | GPIO10 | Reads LS7366R chip select as HOME. |
| Upper final monitor | 28 / GPIO35 | GPIO11 | Reads SPI MOSI instead of limit; desired pin reserved. |
| Lower final monitor | 29 / GPIO36 | GPIO12 | Reads SPI clock instead of limit; desired pin reserved. |
| VFD UART TX | 10 / GPIO17 `VFD_TX_3V3` → U24.A1 → J24.03/VFD RX | GPIO18 TX | Transmits on the line leading to VFD TX; possible contention when translator enabled. |
| VFD UART RX | 11 / GPIO18 `VFD_RX_3V3` ← U24.A2 ← J24.04/VFD TX | GPIO17 RX | Listens on the line leading to VFD RX. Swapping external wires alone does not fix OE or other mapping. |
| SPI CS MRAM/counter | 17 / GPIO9; 18 / GPIO10 | Safety/HOME pull-up inputs | No SPI chip selection or storage/count data path. |
| SPI MOSI/SCK/MISO | 19/GPIO11,20/GPIO12,21/GPIO13 | Two limit inputs; MISO unused | No SPI initialization/transactions. |
| Status LED | 23 / GPIO21 | GPIO48 | Fault indication drives RTC SCL instead; physical LED not controlled. |
| RTC SDA/SCL | 24/GPIO47,25/GPIO48 | Unused / LED output | RTC unavailable; SCL driven as non-I²C output. |
| VFD_ENABLE (OE and run) | 35 / GPIO42 | Not defined | Defaults low; UART blocked and run collector off. |
| Light / auxiliary | 34/GPIO41;15/GPIO3 | Not defined | Outputs cannot respond to commands. |
| Service key/hold/up/down | 30/37,31/38,32/39,33/40 | Not defined | Local service controls have no application path; key pin also reserved. |
| RF D0–D4 | 4/4,5/5,6/6,7/7,12/8 | Top/right/bottom/left/center | Electrical numbers agree; semantic button mapping does not (M08). |
| RF LEARN/TX_ID/MODE_IND | 22/14,8/15,9/16 | Not defined | No pairing control/identity capture/decoder-state feedback. |

### M03 — UART OE and run-permit coupled; neither implemented — blocker

NET `VFD_ENABLE` ties U10.35/GPIO42, U24.8/OE, R24 pull-down, and R25 feeding U25's LED. U25 collector/emitter go to J25.1/.2; LED return is logic GND. It is not an independent watchdog or safety relay. Firmware never sets GPIO42, leaving OE low and therefore translator outputs high-impedance. [TI TXS0104E](https://www.ti.com/product/TXS0104E).

Furthermore, enabling serial communication also asserts the run collector. Disabling run removes serial communication, including STOP/monitor/readback. A simple GPIO fix is insufficient: define separate communication and run-authority behavior (prefer independently controlled hardware paths), drive-terminal semantics, reset levels and sequencing. J24 order **01=5V,02=GND,03=VFD RX,04=VFD TX** matches the user's selection. Its common-ground translator is not galvanically isolated.

### M04 — Module/build/debug/storage target not aligned — blocker for target qualification

`firmware/platformio.ini:1` selects `esp32-s3-devkitc-1` without a pinned platform, flash/PSRAM override, or custom partition selection. Installed board metadata names N8/no PSRAM, uses `default_8MB.csv`, QIO flash and USB hardware mode 1. This default includes OTA-sized app regions and a `spiffs` data partition, but the application implements neither OTA nor filesystem serving. No `ARDUINO_USB_CDC_ON_BOOT` selection was found. ROM USB recovery and runtime serial-console behavior must be tested separately; missing CDC configuration is not proof ROM USB cannot upload. Pin resources, 16MB flash, octal PSRAM initialization, partitions and debug interface need a single explicit target profile. No additional asset-flash IC is required merely because software has not used the module's capacity.

### M05 — USB-only service power claim is false in current schematic

J10 VBUS → U14.1/VIN → U14.6/VOUT → +5V. U20.3/IN and .2/EN are **+12V**, not +5V. Consequently USB alone cannot power U10's +3V3 supply through the designed regulator path. `docs/schematic-capture-readiness.md`, “5 V source sharing,” says either source runs logic; only the 5V rail is shared. Choose and document a USB-powered logic path or explicitly require isolated external low-voltage power for service. Do not rely on parasitic backfeeding through USB data/peripheral pins.

### M06 — Encoder/counter/MRAM paths stop at unimplemented firmware

`Encoder_Counter_RevA` U32 SPI pinout matches the LS7366R data sheet: 4 CS,5 SCK,6 MISO,7 MOSI; 12 A,11 B; 14 +3V3,3 GND. Counter enable and inactive index are high; flag outputs unused. Firmware `onUpPulse()/onDownPulse():73` expects separate up/down pulses at GPIO35/36, not a SPI quadrature count. U31's outputs terminate at U32, not those GPIOs. Merely swapping GPIO definitions will not obtain position. [LSI/CSI LS7366R datasheet](https://lsicsi.com/wp-content/uploads/2021/06/LS7366R.pdf).

U11 PM004MNIATR uses shared SPI with its own CS. No driver exists for either device. Future drivers need per-device transactions, deasserted CS at startup, 32-bit counter configuration and rollover handling, count validity after reset, MRAM startup/mode commands and integrity checks. There are no explicit CS pull-up resistors on U11.1/U32.4 in the export; firmware safe boot configuration and hardware bias need review.

U11.3/.7 are named `~WP/SIO2` and `~HOLD/SIO3`, tied to +3V3. The local Siproin v1.34 pin-description table calls these SIO2/SIO3, not conventional flash WP/HOLD. This is **single-bit SPI only** as wired; do not issue quad/QPI transfers with these pads strapped. The data sheet's unused-pin wording and power-cycle requirements need confirmation before claiming a generic FRAM/flash driver is compatible. It specifies finite endurance (10^8 cycles), so “MRAM” alone does not establish unlimited application write life. See `datasheets/Siproin_PM004MNIATR_4Mbit_SPI_MRAM_datasheet.pdf`, sections 1–3 and 8/11.

### M07 — Floor model, HOME origin and position validity conflict — motion blocker

`LiftConfig.h:22` has **four** floors at 0/20,000/40,000/60,000. UI `:35` has three at 0/18,420/39,250 and `:148` uses fixed 8,000/27,000 thresholds to label the current landing. Editable floor values do not drive that calculation. FW `findFloor():126` always reads constants. Top HOME near floor 3 is documented in `new-controller-requirements.md:26`; FW `:632` sets position zero whenever HOME is active while idle, colliding with floor1=0 and positive higher-floor coordinates.

FW `setup():736` treats missing/corrupt NVS as position zero and can enter idle; there is no position-valid, unknown-position, homing or floor-programming state. A CRC-valid old count is also not proof the car did not move during a power outage. Host tests reproduce invented-zero startup and top-HOME coordinate reset. A controller-owned coordinate model, validity/recovery procedure, configured landings/tolerance and nullable current-floor status are required before normal moves.

### M08 — Five RF buttons have incompatible semantics and arbitration

FW `serviceButtons():681` maps GPIO4/D0 → floor3, GPIO5/D1 → floor4, GPIO6/D2 → STOP, GPIO7/D3 → floor2, GPIO8/D4 → STOP. There is no remote floor1 or light toggle. Exact legacy physical-button-to-D-bit association remains a measurement, but this cannot implement **any** permutation of the required three floors/STOP/light because light is absent and floor4 is extra.

`risingEdge():674` initializes previous states false, so a held HIGH at startup is treated as a new command. Simultaneous floor requests choose code-order winner; later STOP takes precedence in that iteration but can also change Fault to Stopping. RF and HTTP call the same basic request function, but no central source/priority/debounce/release-to-rearm policy exists. LATCH at U41.7 is correctly grounded for momentary outputs; RX_CNTL at .8 grounded is a supported “unused receiver-control mode,” **not an output short**. Validate actual remote baud and full packet/button behavior.

### M09 — Stopping setting is accepted but unused; calibration absent

POST `/api/settings` saves `stopOffsetCounts` (`FW:397`); `requestMoveToFloor():184` copies the fixed floor table's 3,500 instead. Host test saves 17, then verifies active threshold remains 3,500. Run-speed updates are accepted during movement and affect the next run frame. Calibration validity is not invalidated by speed or VFD changes. `serviceMotion():640` takes absolute remaining distance: passing beyond the stopping window makes remaining distance grow, so motion may continue in the original direction. No maximum-travel/progress/time envelope contains this failure.

### M10 — STOP/fault/drive-feedback semantics are unsafe — motion blocker

`VfdProtocol.cpp:isStopAck` searches a substring. FW `serviceVfdRx():610` retains replies received outside Stopping, then consumes any old `(3)84` when a later stop starts. No framing, checksum validation, transaction freshness or RX-echo discrimination. Receiving a command acknowledgement immediately sets Idle; it is not proof physical deceleration/braking finished. Monitor status is never queried/parsed.

`beginStopping():151` accepts a Fault state; a subsequent ACK sets Idle without explicit fault reset. `enterFault():142` sends one STOP then ceases retries and does not remove hardware enable. `serviceMotion()` detects neither prolonged no-count/no-VFD-reply motion nor unexpected idle movement. Missing STOP ACK does cause a two-second timeout fault, but the fault path is not qualified. These are reproduced against real application logic. Missing VFD/counter drivers also mean physical fault detection cannot currently work even if individual state-machine branches pass.

### M11 — Independent safety authority is a requirement, not a verified circuit

J41/J42 monitor circuits and J43/J44 service contacts feed the MCU. No exported path puts their contacts in series with U25/J25 permission, nor is an independent external watchdog/safety controller/brake loop captured. The installation may contain an external chain; this review cannot verify it. It must remain a release prerequisite, not an assumed protection.

FW `initializeVfd():599`, called from `setup()`, writes acceleration, deceleration, timeout and maximum frequency before deciding safety status, with no ACK and no initial STOP. With safety open at boot it enters Fault without calling `enterFault()`; the host observes four parameter writes and no STOP. `/api/reboot` schedules reset even while moving (`:519`, `loop():772`). Pull-downs can establish off states after reset, but do not detect a processor stalled with its output HIGH. No application-owned watchdog/authority-removal logic or proof of independent firmware-lockup shutdown exists.

### M12 — Physical service station has no runtime owner

J43 pins1/2/3 are key/hold/GND; J44 pins1/2/3 up/down/GND. R45–48 feed opto LEDs from +12V; closing a dry contact sinks the LED current and pulls the corresponding 3.3V collector LOW via U43, with R53–56 pull-ups. No FW pins/state/jog/timeout/conflicting-direction handling exists. UI `serviceMode` at `:106/:294` is local display state only. Key + hold + direction must be sampled continuously by firmware, combined with independent safety permission; releasing any required input must stop. Web service configuration cannot grant local physical authority.

### M13 — VFD routes compile but lack completed transactions and strict validation

FW routes `:425/:450` return 202 with literal `readbackParsing:"pending"` or `readbackVerification:"pending"`, but there is no asynchronous completion store/poll/readback implementation. GET can send UART during movement without authentication or a transaction arbiter. POST has idle/range/read-only checks but no distinct installer/advanced authorization despite metadata labels.

Parameter number is narrowed to uint8 before validation: 266 becomes FMAX10. `toInt()` accepts numeric prefixes. Parameter13 read behavior in original manual p30 is input1/input2/input3/relay digit status, whereas the single metadata definition calls it boolean RELE. Startup overwrites ACC/DEC/TIME/FMAX every reset (1s/1s/0.1s/120Hz), undermining persistence of drive tuning. The 100ms command refresh equals the requested 100ms drive timeout, leaving no demonstrated scheduling/wire-time margin. No receive health, bus voltage/current/temperature/overload alarm or calibrated load-limit behavior is implemented.

### M14 — API validation, versions and errors are not a complete contract

FW `/api/move` at `:540` narrows `toInt()` to uint8: floor258 becomes floor2; `2junk` also succeeds. Motion rejection is generic `{error:"move_rejected"}`, not the documented reason/message. Settings silently ignore advertised `homingTimeoutMs`/`logRetentionRecords` updates and have no per-field unknown-key rejection. Inputs are query/form arguments, not a general JSON body contract.

UI `apiFetch():112` verifies only HTTP success and JSON content type; no runtime schema/API revision/capability validation, timeout/AbortController, or out-of-order response guard. An empty JSON object reaches rendering and crashes in simulation. UI collapses controller error details into generic messages and ignores move/stop response state before polling again. Firmware emits signed 64-bit counts as JSON numbers, but JS Number is exact only through 2^53−1: choose an explicit bounded count domain or string encoding for the long-term contract.

### M15 — UI can present false operational feedback — blocker for operator use

UI `:101/:103` initializes healthy demo data with `demoMode=false`, displaying Controller online before contact. A failed poll at `:121` sets demoMode but preserves prior real status; `lastUpdated` changes even on failure. At `:176`, STOP in demo mode changes state locally without attempting `/api/stop`. The handler test establishes live moving status from real firmware JSON, disconnects, presses STOP and observes local Idle with no outgoing request. A demo move timer at `:164` can later overwrite reconnected live data.

`UI:248` derives “All interlocks healthy” only from safetyOk. `:298` always says drive Communicating with fixed values, even on failed API. `:276` equates Idle to stationary/ready despite firmware's ACK weakness. These must become explicit connecting/stale/offline/preview states with authoritative permission and freshness. Preview must be opt-in and isolated from a previously connected machine. Web STOP is still not an emergency-stop circuit.

### M16 — Most visible controls are not connected

Only four UI `apiFetch` paths exist: status, move, stop, light/toggle. Firmware has no light route or GPIO driver, so that one returns 404. `SetupPanel:337`, `DrivePanel:369`, `RemotesPanel:391`, `LogsPanel:436` and `SystemPanel:440` largely use local state/toasts/sample data. No live floor save, speed save, calibration, VFD page read/write, RF API, persistent log rendering/CSV, network editing, backup/restore or reboot call is wired from those panels. Unsupported controls remain usable when basic status connects. “Calibration is current,” decoder-erase-complete and configuration-backup-prepared messages are not hardware results.

### M17 — RF configuration/timing contract incomplete

JP41/42 strap decoder baud; there are no pull resistors on their center nets, so unpopulated shunts leave inputs floating. Define assembly defaults and verify legacy rate. RXM-LR is rated to 10kbps; not every selectable decoder rate is usable through this receiver. FW does not configure a receiver for TX_ID or GPIO drivers for LEARN/MODE_IND. The browser's 17-second timer is not a 17-second HIGH command: learning uses a momentary LEARN assertion, whereas holding it HIGH for ten seconds clears memory. Separate bounded controller transactions and physical feedback are required. Linx also specifies 2.0–5.5V decoder supply and permits grounded RX_CNTL when unused, so U41 at 3.3V and .8 at GND are not defects. [Linx-authored decoder manual, mirrored PDF](https://datasheet.octopart.com/LICAL-DEC-MS001-Linx-datasheet-132900.pdf).

### M18 — RF identity is a reusable slot, not a permanent transmitter ID

The same Linx manual's TX ID section specifies an eight-bit learned-order number transmitted at the selected baud. Slots can be reused/overwritten. UI sample 32-bit-looking IDs and documentation about restoring names when an “ID” reappears must not be taken as stable physical identity. Include a decoder learning/erase generation and explicit re-association policy; restoring a profile and merely seeing the same slot can associate the wrong remote. No registry firmware exists yet. This is a contract-design finding, not a claim that a currently implemented registry corrupts data.

### M19 — Persistence/logging/defaults/versioning stop at substitutes

`PositionStore.cpp` stores one CRC-protected raw struct in NVS `lift/state` (magic LFT1, version1). `LiftSettings.cpp` similarly uses `settings/lift` (LSE1, version1). No sequence/redundant record, last-motion marker, floor configuration, calibration provenance or recovery validity. Raw C++ layout/padding is not a portable versioned wire/storage format; host CRC tests do not certify target ABI or power-loss atomicity. `servicePersistence():699` writes every250ms and ignores failure. No retention/wear budget is calculated for actual writes.

`NetworkConfig` CRC record lacks explicit schema version; credentials are stored, not returned, but `jsonNetworkStatus():309` fails to JSON-escape SSIDs. `EventLog.h` capacity is32 RAM records despite advertised2048; reset erases events; milliseconds are not RTC timestamps. Fault events omit reason/source; “MotionStopped” is logged when STOP is requested. UI event schema `{title,time,detail,level}` does not consume firmware `{seq,ms,code,a,b}`. Firmware speeds default45/25/20Hz, UI displays45/10/8; saved stopping offset is not used (M09). No config backup/restore implementation or migration exists.

### M20 — Network servicing and command authority lack timing/security qualification

AP fallback and optional STA/mDNS code exists, but real connection/recovery was not tested. AP is disabled when STA connects, so “AP primary service path” should not imply always-on access. Built-in diagnostic HTML at FW `:338` sends writes without the token header, making its buttons fail when auth is configured. `Secrets.example.h` permits empty API token; the host suite explicitly uses a nonempty test token. Deployment credential policy is not established by this review. No separate roles, request-origin/CSRF policy or audited client identity exists.

FW `loop():764` calls synchronous `server.handleClient()` before motion servicing. In the installed Arduino2.0.17 library, `WebServer.h:49` has 5s data/POST/send waits; `Parsing.cpp:45` waits for body data with `delay(1)` before returning. Thus “nonblocking motion loop” is not a proven end-to-end responsiveness guarantee. Slow-client/body tests and a bounded scheduling architecture are required, especially with a100ms VFD timeout. This is source evidence of a blocking path, not a measured MCU latency result.

### M21 — Web bundle/update mechanism not installed in firmware

Embedded Vite build succeeds; FW GET `/` returns a small inline diagnostic page, not the React console. No filesystem mount, asset handler, gzip/cache/MIME handling, SPA fallback, firmware update route or filesystem build/upload step exists. The cloud/Vinext build is not a substitute for same-origin MCU API hosting; no proxy/remote-device bridge was verified. A controller-hosted deployment and version-compatible rollout/rollback contract must be implemented and tested.

### M22 — Schematics and PCB net identity agree, fabrication readiness does not

Fresh parity list is empty, but343 connections are unrouted. Matching net assignments do not physically connect pads. DRC library differences and silkscreen findings need reconciliation, not a blanket waiver. Claimed 90mm envelope/86mm mounting centers do not establish screw diameter, actual clearances, wire-bend access, U.FL/SMA cable paths, thermal/EMI suitability or protective-earth integrity. A numerical netclass clearance is not a safety-standard qualification.

### M23 — Component/package and library claims need correction before assembly

NET D41/D42 values are **SMBJ15A** but footprints are `Diode_SMD:D_SMA`; D20 with the same value uses `D_SMB`. SMBJ15A is an SMB/DO-214AA package, so D41/D42 part-to-land-pattern assignments disagree. Select/verify the actual TVS package and polarity and then update through Konnect, not by blindly refreshing all footprints. [Manufacturer SMBJ15A package](https://www.aosmd.com/products/tvs/high-power-tvs/smbj15a).

D40 is generically “BAT54” with `D_SOD-323`: obtain the full manufacturer/package suffix rather than assuming all BAT54 variants match. `ED300/3` remains an Altech substitute land pattern; Phoenix1717732 is explicitly provisional. U11/U32/RTC and U10 exposed-pad segmentation need drawing-based qualification. `component-library-request.md` still calls RTC footprint LGA-8_2x3mm, while NET is `MicroCrystal_C7_SON-8_1.5x3.2mm_P0.9mm`; it lists TPD2EUSB30DRTR while NET U12 is **TPD2EUSB30ADRTR**. Downloaded-library presence is not independent pinout verification.

### M24 — Field “isolation,” polarity and timing assumptions need qualification

Encoder/safety/home/service optos share **GND** between field connectors and transistor returns. They offer optical signal transfer/level conditioning but do not form a galvanic isolation boundary for those ports. Independent mains isolation is a different function. Firmware active-low assumptions match opto collector behavior in principle, but are attached to wrong GPIOs; exact NC/NO contact semantics, shorts-to-GND and cable-open diagnostics remain unresolved.

Encoder R30/31=2.2k implies roughly5mA when sinking at12V (estimate using~1.2V LED drop), not the legacy270-ohm loading. U30 timing/CTR at that current and R32/33=10k collector pull-ups may limit edge fidelity; the4MHz counter clock does not guarantee the opto front end passes the required rate. No actual encoder max speed/PPR/cable trace was captured here. Both quadrature channels are optically inverted then Schmitt-inverted, but direction/sign still needs physical verification. No firmware filter/error budget currently exists.

### M25 — Supply and load protection are not yet coordinated

RAC10-12SK/277 is12V/840mA nominal; a750mA lamp leaves90mA at12V before controller/converter/encoder/input loads. Prior successful lamp operation is useful evidence but not a Rev-A combined-load test. F21 is0.75A hold and carries all onboard12V current, including the onboard-selected lamp; its hold rating equals the lamp estimate before other loads. Thermal derating and inrush can matter. JP40 allows an external lamp supply; test/select it based on measured margin rather than silently replacing the user's chosen AC/DC module.

F20/MOV/R21 supply-return link, fuse interrupt rating/inrush coordination, regulator thermals, output TVS/clamp/load behavior and external-supply grounding need qualified values. J20.3/CHASSIS connects USB shields; it is not a documented protective-earth bonding scheme for the enclosure. The safety review must cover the complete installation, not just PS20's module certifications. See local RECOM data sheet selection/load tables and NET Power/IO.

## API contract inventory

| Interface | Actual firmware result/body | UI today | Compatibility/completion |
| --- | --- | --- | --- |
| GET `/api/status` | 200, state/counts/targetFloor/speed/safety/home/limits/last-command/fault/network | Poll3s; same field names | Data shape tested; semantics/freshness/permission incomplete. No version, capabilities, validity, VFD health, light state. |
| POST `/api/move?floor=N` | 202 status,401 unauthorized,400 missing,409 generic rejected | Uses route/header | Partial; narrowing/validation/prechecks and reason handling defective. |
| POST `/api/stop` | 202 status or401 | Uses route unless preview mode | Partial; fault latch and offline handling unsafe. |
| POST `/api/light/toggle` | Absent | Expects JSON `{on}` | Incompatible/404. |
| GET/POST `/api/settings` | GET six fields; POST accepts four numeric form/query fields, saves NVS | Local-only setup | Partial; fields/defaults/actual motion settings disagree. |
| GET `/api/vfd/parameters` | Definitions with min/max/default/scaling/access, no live values | Static table | Planned connection; metadata is not readback. |
| GET/POST `/api/vfd/parameter` | 202 sent/pending; POST has idle/range/read-only/auth checks | No calls | No completion/readback protocol or displayed result. |
| GET `/api/logs/recent` | Array of at most32 numeric-code/millisecond RAM events | Static event models | No adapter/fetch/persistence/pagination/CSV. |
| GET/POST `/api/network` | Status/write-auth flag; stores form/query SSID/password,202 restartRequired | Editor toast only | API partly implemented; unsafe JSON string construction and real recovery untested. |
| POST `/api/reboot` |202 schedules restart after1s | Toast only | No live UI path; FW accepts moving state. |
| Floors/remotes/learn/erase/calibration/config backup/restore/recovery | Absent | Local preview or disabled explanation | Planned; must not be advertised as operational. |
| GET `/` / static assets / OTA | Inline diagnostic HTML / no React asset handler / no OTA handler | Separate web build | No integrated shipping/deployment mechanism. |

## Control authority and failure behavior

| Decision or failure | Intended owner | Present behavior | Required boundary |
| --- | --- | --- | --- |
| E-stop, final limits, brake/drive inhibit | Independent hardwired equipment | External topology unverified; board only monitors contacts plus one MCU-driven collector | Establish/test independent removal with MCU unpowered/stalled. Never grant this authority to UI/RF alone. |
| Normal motion acceptance | Firmware supervisor under hardwired permission | Idle+safety+known constant floor only | Add valid position/calibration/drive health/directional limits/conflicts, re-evaluate continuously. |
| Web/RF/local priority | One firmware arbiter | HTTP then RF code-order handling; service absent | Deterministic STOP/fault priority, source tagging, release-to-rearm and simultaneous-input policy. |
| Keyed service | Physical key+hold+direction, firmware limits, external safety | No driver/state; UI toggle changes only local state | Local continuous consent, bounded speed/time, no remote normal moves or safety bypass. |
| Communications loss | Firmware drive-health supervisor and independent inhibit | Continues run without replies; only stopping timeout exists | Freshness deadlines, deterministic fault/stop/inhibit; verify real drive timeout independently. |
| STOP complete | Firmware based on fresh response plus stopped evidence | Substring ACK immediately becomes Idle | Distinguish command accepted, decelerating, stopped, fault; validate physical position stability. |
| Browser disconnected | UI must withdraw claims, firmware remains authoritative | Automatically enters demo; STOP may be local-only | Explicit offline state, no invented success, bounded best-effort operational STOP feedback. |
| Reset/brownout/reboot | Hardware defaults plus controlled firmware startup | GPIO pull-downs present; app overwrites drive parameters, assumes restored/default position; moving reboot allowed | Boot inhibit, source reconciliation, no unintended startup command, power-loss validity and controlled restart. |
| Storage/sensor failure | Firmware validity/fault supervisor | NVS failure ignored; encoder/sensor validity absent | Fail closed for normal motion, explicit logged recovery, no fabricated zero/calibration. |

RF authentication by the decoder is not equivalent to safety permission; the Linx receiver guide itself warns against treating radio data as an independent safety mechanism. UI disabled buttons are not protection against direct API/RF/local requests. Current electrical interlocks do not demonstrate a safety-rated enabling device or certified lift controller.

## Prioritized integration backlog

All entries are proposals, not applied fixes. P0 blocks operator/motion integration; P1 blocks a functional Rev-A release; P2 addresses verification/documentation after foundational decisions. “Blocker” describes dependency/unsafe integration, not an instruction to energize hardware after one fix.

| Priority/type | Work item and references | Acceptance condition / dependency |
| --- | --- | --- |
| P0 blocker B1 | Freeze N16R8-compatible pin/peripheral contract; M01–M04 | No reserved pins; firmware/generated pin map agrees with NET; UART roles correct; explicit board target. Konnect `edit_schematic_component`/wiring tools for approved changes, then export/compare/ERC/DRC. |
| P0 blocker B2 | Separate serial availability from motion permission and define independent hardwired chain; M03/M11 | Drive can remain inhibited while STOP/monitor/config communicates; stalled/unpowered MCU cannot sustain permission; externally reviewed wiring/terminal semantics. |
| P0 blocker B3 | Implement valid-position + counter + guarded motion/fault state machine; M06–M10 | Unknown-position startup; top-HOME model; no movement without progress/drive health/calibration; no overshoot continuation; no STOP fault bypass. B1/B2 first. |
| P0 functional defect F1 | Fresh framed EM01 parser/transaction manager, stop completion, watchdog timing; M10/M13/M20 | Reject stale/invalid/echo replies, serialize reads/writes, bound retries; actual stopped evidence and loop timing under client load. |
| P0 functional defect F2 | Remove automatic live-to-demo transition; M14/M15/M16 | Offline never reports physical success/idle; cancel isolated demo timers; schema/capability/freshness validation; truthful telemetry and error display. Required before operator-facing use. |
| P0 blocker B4 | Resolve PCB/package/mains readiness; M22–M25 | D41/D42 correct package, qualified connectors/critical footprints, completed routing, reconciled DRC/library differences, independent mains/earth/mechanical review. No manufacturing release before this. |
| P1 functional defect F3 | Strict API validation/reboot/settings permissions; M09/M13/M14/M20 | Reject wraparound/junk/unknown fields; idle/authority guards; no moving restart; meaningful reasons; explicit auth/role/origin policy. |
| P1 implementation I1 | PM004MNIATR/RTC drivers and versioned persistence; M06/M19 | Shared-SPI tests, power-cycle recovery, sequence/CRC records, validity semantics, finite-write budget, real timestamped durable logs. |
| P1 implementation I2 | Floor programming, homing and measured calibration; M07/M09 | Three authoritative landings, top reference, bounded calibration sequence, direction/scale and tuning provenance, stale-calibration inhibition. Depends on B3/F1/I1. |
| P1 implementation I3 | RF mapping/identity/learn/erase and arbitration; M08/M17/M18 | Five required actions, verified baud/slot capture, bounded learn vs erase, generation-aware registry, logs, no unintended boot/repeat/conflict commands. |
| P1 implementation I4 | Local service controls; M12 | Key/hold/direction continuously enforced; simultaneous up/down rejected; release/timeout/fault removes command; normal RF/web moves unavailable throughout service. Depends on B2/B3. |
| P1 implementation I5 | Light/optional auxiliary drivers + API; M16/M25 | Safe reset polarity, authoritative state, predictable retries/multi-client behavior, measured supply/load. State-setting preferred over untracked toggle. |
| P1 implementation I6 | Self-hosted UI and remaining endpoints; M16/M19/M21 | Versioned same-origin assets, bounded transfer handling, actual panel reads/writes, no mock success; explicit update/rollback policy. |
| P1 verification V1 | Encoder/VFD/RF electrical/baud/latency tests; M24/M17/M13 | Recorded scope/logic-analyzer traces and configured constants; test plan below. |
| P1 verification V2 | Combined power, USB service, source loss and brownout; M05/M25 | Documented power budget and supply selection; no backfeed, reliable boot, no unsafe outputs. |
| P1 verification V3 | Independent safety and integrated acceptance | Qualified external review plus witnessed results under controlled, separately authorized procedures. Software tests do not replace it. |
| P2 documentation D1 | Update claims listed below after decisions, not before | Requirements distinguish current implementation from target, exact parts/pins/API schemas, verified test records and revision IDs agree. |
| P2 verification V4 | Clean-clone portability and repeatable dependencies; M04/M23 | Destination KiCad standard/project libs and LFS assets resolve; lock/pin toolchain; CI runs contract/behavior tests, not just builds. |

### Documentation conflicts and stale claims

| Document/section | Claim versus verified state | Proposed correction |
| --- | --- | --- |
| `README.md` Hardware architecture/service station; `hardware/README.md` assumptions | “Optically isolated” field inputs share GND. | Describe optocoupled level conditioning/common reference; separately name true isolation boundaries. |
| `docs/schematic-capture-readiness.md`,5V sharing | Either USB/onboard source runs logic. | USB powers5V only in current NET; 3V3 requires12V. |
| `docs/component-library-request.md` | RTC LGA footprint; TPD2EUSB30DRTR; blanket verified/imported wording | Actual RTC C7 SON footprint, U12 ADRTR, explicit verification status per critical part; add D41/D42 and D40 package qualification. |
| `hardware/reports/schematic-review-summary.md`, light gate | Requires external lamp feed unless larger AC/DC used | Newer field/selection docs allow RAC10 with measured margin; retain measurement gate without silently mandating a larger supply. |
| `hardware/README.md:50` | “0.8mm SELV power routing” can be read as clearance | Readiness report says0.8mm track/0.2mm clearance; label widths versus clearances explicitly. |
| `docs/hardware-requirements-matrix.md`, MEM-003/PWR-003/ENC-002 | Optional QSPI/SD decision,5V RF load, legacy270Ω front end | RevA asset flash is module-internal; RF actually3V3; current2.2k frontend is deliberate but unverified, not a literal copy. |
| `hardware/architecture-blocks.md`, encoder/reference/flash chip selects | Reference architecture still mentions legacy passives/flash selection | Keep historical observation distinct from current captured net/pin contract. |
| `docs/snapeda-library-import.md` | Historical refdes/package statements | Reconcile against current J10 USB, U41 decoder footprint and corrected assets; do not treat import history as live BOM. |
| `README.md` starter/API descriptions | “Nonblocking” and “stopped-only” may overstate guarantees | Some handler/body paths block; Idle does not establish physical stopped; readback is pending forever. |
| `webapp/docs/api-contract.md` | Preview-on-failure rule permits risky connected-to-preview transition | Separate opt-in demonstration from offline live controller; define validity, capabilities, errors and completion. |
| `webapp/docs/firmware-integration-gaps.md` | Correctly requires authoritative state and unsupported controls disabled | Requirements are still **not implemented**; link concrete tests and tracked fixes instead of implying the handoff resolved them. |
| `docs/new-controller-requirements.md`/UI remote restore text | Observed ID reappearance treated as remote identity | Learned-slot reuse needs generation and re-association; not a permanent transmitter identifier. |

Older readiness reports' numerical ERC/DRC results largely reproduce. Their limited “bench planning, not manufacturing” conclusion remains appropriate; they do not establish software compatibility. No historical documentation was rewritten during this review, preserving evidence and the user's review-only boundary.

## Remaining integration test plan

Environment labels: **S** simulation/host; **L** powered isolated low-voltage logic board/development fixture; **P** peripheral fixture with drive motion physically inhibited/disconnected; **A** assembled system under a separately authorized, qualified procedure. No L/P/A tests were executed here. Never run current `setup()` against a real VFD merely to read parameters: it writes settings on startup. Build a read-only/simulation fixture first. Power-board tests should use an isolated current-limited low-voltage source with the mains section disconnected until a qualified mains procedure exists.

| Test / gaps | Prerequisites | Procedure | Expected acceptance result | Environment |
| --- | --- | --- | --- | --- |
| T01 Pin/variant contract (M01–04) | Approved N16R8 mapping and Konnect updates | Export NET; compare every GPIO/peripheral/polarity to firmware config; compile target; assert no reserved pins | Exact agreement; no accidental UART reversal/CS/LED conflict; expected16MB/8MB configuration | S, then L for identification |
| T02 Power/USB-only (M05/25) | Qualified passive BOM, low-voltage fixture, current limiter, no drive | Apply12V alone, USB alone, both, remove each; record3V3/5V/12V, reverse currents, EN and resets | Behavior matches declared service-power design; no parasitic boot/backfeed/unsafe output; stable rails at load | L |
| T03 Boot/reset/watchdog (M03/11) | Separate inhibit/serial design; dummy load; scope | Reset, BOOT mode, software stall, watchdog, brownout, failed NVS, safety-open boot | Inhibit remains safe; no startup RUN/unapproved settings; unknown position blocks normal motion; recovery explicit | S + L/P, drive disconnected |
| T04 SPI coexistence (M06/19) | Counter/MRAM drivers, CS bias/config | Alternate transactions, reset either peripheral, inject timeout/all0/all1 MISO, vary SPI rates/modes | No bus contention; device-specific modes/readback; failures invalidate motion state, not fabricate position | S + L |
| T05 Encoder bandwidth/polarity (M24) | Exact encoder/PPR/maxRPM/cable data, pulse generator, counter driver | Sweep A/B phase/rate/duty/noise; test open/short/stuck channels; compare generated count with raw/clean/counter count | Upward sign correct; no lost/reversed counts at specified margin; faults for invalid/progress-loss cases | S + P |
| T06 Counter wrap/reset/time continuity (M06/07) | Defined count domain and valid-position model | Cross32-bit limits both directions; MCU-only/counter-only reset; reboot during movement; corrupt restored snapshot | Coherent signed count/rollover; uncertain motion produces unknown-position, never invented zero | S + L |
| T07 Safety/limit truth table (M02/11/24) | Approved NO/NC and wiring diagnosis, external chain drawing | Inject each contact/open cable/short-to-GND; both limits; each travel direction; test with MCU removed/stalled | Correct polarity; explicit blocked reasons/direction permissions; independent circuit removes authority without app | S + L/P; external chain final A |
| T08 Service station (M12) | Service state machine and physical controls | Exercise key/hold/up/down combinations, release, both directions, timeout, reset and web/RF calls during service | No motion without all required local conditions; release/fault/timeout stops; remote normal commands rejected/logged | S + L/P; final A |
| T09 EM01 frames/transactions (M10/13) | Parser/arbiter, UART emulator, verified manual | Fragment/concatenate/corrupt frames; inject echo/staleACK/lateACK, dropped replies, alarms, wrong response types | Only complete verified fresh matching responses accepted; bounded failure; ACK not equated to stationary | S + L/P |
| T10 UART electrical/enable timing (M02/03) | Correct GPIO mapping and independent permit, scope | Verify J24 pinout/idle voltage, TX/RX with emulator; OE/run sequencing with drive inhibited |9600 8N1 correct direction/levels; no output contention; monitor/config while inhibit stays safe | L/P |
| T11 Control responsiveness (M13/20) | Scheduling budget, non-motion UART sink, network test host | Slow POST/header clients, stalled downloads, many polls, Wi-Fi loss, flash writes under synthetic motion | Measured worst-case loop/stop latency below approved deadline with margin; independent inhibit works during stalls | S for bounds; L for real RTOS/network |
| T12 Motion edge cases (M07/09/10) | Validity/supervisor fixes | Simulate zero progress, wrong direction, overshoot beyond window, unexpected idle drift, target-current equality, conflicting calls, lost VFD | Deterministic rejection/fault/stop; no runaway continuation or fault reset by STOP; all sources share rules | S first |
| T13 Physical deceleration and calibration (M07/09) | All P0 fixes; proven safety/limits; qualified procedure and travel clearance | Program three floors/top HOME; measure stopping in both directions/load cases; alter speed/decel/scale; interrupt calibration | Safe bounded motion, recorded actual stop distance/provenance, invalidation/recalibration, landing tolerance satisfied | S sequence first; final A (new authorization) |
| T14 MRAM/persistence (M06/19) | Driver/schema/write budget, controllable supply | Save/reload versions; random power cuts during records; corrupt/partial writes; full log; migration/restore failures | Latest complete record or explicit invalidity; sequence/CRC; no flash-style unsafe quad use; endurance/retention budget | S + L |
| T15 RTC (M02/19) | Driver and qualified J12 backup | Remove main power, set invalid time, battery absent/depleted, I²C stuck, MCU reset | Correct timestamp/time-valid marker; bounded bus recovery; no false date or motion on backup | L |
| T16 RF commands/baud (M08/17) | Known remotes, shunt settings, logic analyzer, no drive | Map every button to D0–D4; held-at-boot, repeated/overlapping presses, range/noise/interference, baud mismatch | Exactly floor1/2/3/STOP/light; no phantom startup/release command; RF loss cannot be safety sole path | S + P |
| T17 RF learn/erase/identity (M17/18) | Spare/test decoder or approved test memory; controller transactions | Momentary learn/cancel,17s timeout,10s erase/cancel, reset midoperation,40-slot reuse and backup replay | Hardware MODE_IND/result confirms action; no accidental erase; slot-generation/name association correct | S + P; destructive decoder erase only separately approved |
| T18 Light/aux loading (M23/25) | Correct TVS package/polarity, actual lamp, fuses and source choice | Dummy load then actual lamp inrush/dimming if applicable; both JP40 positions; rapid toggles, two clients, reset | Safe-off boot, no rail collapse/thermal trip, authoritative consistent output state and predictable retries | L/P |
| T19 UI/API negative integration (M14–16) | Mock HTTP server with actual contract; real browser tests | Delay/reorder/drop replies,401/409/500/404, wrong-version JSON,{}, invalid fields; disconnect moving then STOP; reconnect during demo timer | No false online/telemetry/idle/success; controls capability-gated; stale clearly marked; reasons preserved | S/browser, then L |
| T20 Web deployment/update (M04/21) |16MB partitions, asset serving/package process | Offline AP load, gzip MIME/cache/SPA/API404 separation, concurrent clients, firmware/UI versions, interrupted update/rollback | Console truly served by board; API never replaced with HTML; bounded control latency; recoverable compatible update | S + L |
| T21 API/config/arbitration (M13/14/19/20) | Strict parser/auth/schema and supervisor | Invalid numbers/overflow/negative/junk, unknown keys, huge body, JSON vs form, moving settings/reboot, unauthorized origins, restore conflicts | Correct status/reason, no partial commit or unsafe action; credentials excluded from exports; audit source/result | S + L |
| T22 Clean-clone/PCB/library (M22/23) | Destination KiCad10 standard libraries + Git LFS, qualified assets | Clone/copy root; open `hardware/ElevatorLift.kicad_pro`; resolve all footprints/models; rerun ERC/DRC/parity after routing | No machine-specific dependencies; no unresolved required parts or unreviewed DRC; correct component geometry | S/desktop, unpowered board/mechanical check |
| T23 Installation qualification (M11/22/25) | Qualified reviewer; approved mains/earth/EMI/enclosure/braking procedures; all earlier gates | Independently inspect/test AC tap/disconnect, fuses, separation, PE, cable routing, independent stops/fault recovery and loaded travel | Signed installation acceptance and recorded measured behavior; no reliance on UI/RF as safety chain | A, outside this review's authorization |

## Recommended next integration milestone

First produce a **non-motion controller integration baseline**: approved N16R8 pin map, isolated logic power, serial communication available while drive permit remains off, real counter/MRAM/RTC access, unknown-position boot, truthful versioned status API, and UI with no automatic demo fallback. Prove it with synthetic inputs/UART before connecting a real drive. Then implement normal motion, top-HOME/calibration, RF and service arbitration behind the same supervisor, and only proceed to assembled-system testing after independent safety and PCB release gates are closed.

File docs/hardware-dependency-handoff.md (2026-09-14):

# Hardware Dependencies For Software Integration

Updated 2026-09-13. Software now uses contract v2,
`rev-a-2026-09-13-diagnostics-inhibited`. See the
[pin/comms/four-layer handoff](reviews/2026-09-13-pin-comms-fourlayer.md)
and its fresh exported connectivity evidence. Historical 2026-09-10 exports
remain historical; the software contract test now checks the finalized mapping evidence.

**HW-01 and HW-02 are closed at schematic/connectivity level only.** Live PCB
pad checks agree with the new export, and synchronization is a no-op. Firmware
motion integration and physical qualification gates remain open. Do not flash the old
profile: its AUX initialization drives GPIO3 LOW, now a SERVICE_KEY input.

| ID | Required decision / correction | Current software behavior | Evidence needed to close |
| --- | --- | --- | --- |
| HW-01 | Schematic closed: LIMIT_UP GPIO43/p37 through 1k R62; LIMIT_DOWN GPIO44/p36; SERVICE_KEY GPIO3/p15; GPIO35/36/37 NC | Adopted by v2; AUX removed; UART0 application console/logging disabled before input setup | Input truth tables/continuity; GPIO43 ROM boot-output and GPIO3 key/reset/rail-sequence tests |
| HW-02 | Schematic closed: GPIO42 VFD_COMMS_ENABLE connects only U24 OE and R24 pulldown; R25/U25/J25/TP26 removed | LOW at setup, HIGH after UART1 initialization for diagnostics only; no RUN or WRITE path | Verify STOP/readback with external hardwired safety open; reset/brownout/watchdog and independent external authority tests |
| HW-03 | Electrical closure-to-GND = MCU LOW confirmed; installed NO/NC, wire-fault behavior and independent final limits unresolved | Safety LOW=healthy; limits/key use active-low stability filtering, but FieldContinuityQualified=false. Broken limit wires can resemble clear limits | MB-01/03/04 in the external-box review; actual field contact schedule and independent final-limit trace |
| HW-04 | Confirm encoder polarity/scale and field conditioning; exported U32 LS7366R has 4 MHz local clock | SPI mode0, 1 MHz, x4/32-bit/free running; position stays invalid after reset | A/B phase, maximum rate, count-per-travel, filter latency, reset/power-loss behavior; safe no-motion encoder simulation |
| HW-05 | JP41 BAUD0/U41.3 and JP42 BAUD1/U41.4 verified; 1-2=LOW, 2-3=HIGH. Installed diagnostic shunts and D40/learn qualification remain open | Configurable diagnostic baud defaults to 9600; D0-D4 map is floor 1, light toggle, floor 3, floor 2, STOP. Physical mapping remains unverified | Match diagnostic jumpers to UART configuration, not remote timing; verify TX_ID, MODE_IND and learn/erase behavior. U41.7 is grounded for momentary active-HIGH outputs |
| HW-06 | Verify 12 V load budget, JP40 onboard/external supply selection and light output wiring; review remaining D41 footprint mismatch (D42 removed) | Light set-state GPIO41; AUX removed, GPIO3 input-only; no physical load feedback claimed | RAC10 baseline/peak load, upgraded-light external-supply selection, MOSFET protection/polarity and GPIO3 reset review |
| HW-07 | Confirm native USB recovery power path | USB19/20 reserved; build uses native USB CDC | Current export USB VBUS feeds 5 V but not the 3.3 V logic rail; define approved low-voltage bench power procedure before connecting a board |
| HW-08 | Verify RV-3028 backup source and configuration | Read-only UNIX time, POR invalidation, nullable timestamps | J12 backup power, permitted trickle-charge policy, power-loss retention test; no automatic EEPROM/charger writes |
| HW-09 | Confirm PM004 exact revision/mode defaults and SIO2/SIO3 strapping | Verify ID/mode registers, zero-latency SPI only; aligned 16-bit-word accesses | Local V1.34 sheet and assembled device behavior, unused-QPI-pin recommendations vs exported pulls, interrupted writes and retained memory |
| HW-10 | Routing/ERC/DRC, mechanical dimensions, connector access and antenna | Nothing marked manufacturing/deployment ready | Resolve review violations/unrouted nets and physically measure cabinet/90 mm outline/mounting/clearance |
| HW-11 | External keyed override and independent stopping/brake authority are not evidenced; cargo-only operational profile blocked | Diagnostic-only v2 remains inhibited; healthy SAFETY_MON cannot identify override, and SERVICE_KEY is not verified override feedback | External-box review MB-01 through MB-05: bypass/contact schedule, independent E-stop/final limits, VFD command precedence, brake behavior and fault response; subsequent qualified physical tests |

The field-used TXS0104E translation topology is not being rejected or silently
rewired. HW-02 concerns the *additional coupling to run permission*, not merely
UART logic levels. Preserve the independent hardwired safety chain in every option.
No firmware workaround may assert RUN just to obtain telemetry or parameters.
The board no longer provides an MCU-driven RUN collector. The external VFD
configuration and hardwired safety circuit must still be verified to prevent
serial commands from bypassing that authority.

## Software Adoption And Remaining Bench Gates

The mapping, input setup, UART0 suppression, and diagnostic UART items below are
implemented in v2 and regression-tested on host. GPIO HIGH alone cannot establish
wire continuity: `FieldContinuityQualified` remains false and no motion is allowed.
The active-low switch NO/NC arrangement and power-loss detection require physical
review; debounce is not a substitute. No eFuse or bootloader reconfiguration occurred.

- Contract v2 and generated PinMap adopt the new export; keep them synchronized.
- GPIO3/43/44 are inputs and AUX handling is removed. Preserve the
  existing active-low conventions, with unknown/unvalidated inputs inhibiting motion.
- UART0 application console use is disabled; J11 pins 3/4 are NC. Native
  USB programming remains available, subject to the existing bench-power gate.
- VFD_COMMS_ENABLE separates communication availability from motion permission.
  Preserve GPIO42 LOW at startup, then enable UART for STOP/readback
  independently of the safety state. A transmitted STOP is not proof of stopping.
- Keep default JTAG eFuses: GPIO3 is externally pulled HIGH when the key is open
  and LOW when closed. Do not enable GPIO3-controlled pad-JTAG selection; it can
  repurpose GPIO39-42. No eFuses were changed during this work.
- Keep uploads/motion inhibited until prototype reset, input, communication,
  external safety-authority, and remaining hardware gates are qualified.

## Physical Verification Boundary
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

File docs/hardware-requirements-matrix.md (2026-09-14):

# Hardware Requirements Matrix

This matrix converts the project goals into schematic-facing requirements. `TBD` items must be answered before the first PCB revision is finalized.

## Core Control

| ID | Function | Required behavior | Captured implementation / requirement | Key constraints | Open decisions |
| --- | --- | --- | --- | --- | --- |
| MCU-001 | Main controller | Run motion state machine, WebUI, VFD protocol, storage, RF input, diagnostics | `ESP32-S3-WROOM-1U-N16R8` | Wi-Fi AP/station, external antenna, 16 MB flash, 8 MB PSRAM, enough SPI/UART/I2C | Confirm external antenna cable and enclosure feedthrough |
| MCU-002 | Debug/programming | Firmware upload and serial debug | Vertical `USB4145-03-0230-C_REVA2` USB-C to ESP32-S3 native USB, plus J11 boot/reset header (pins 3/4 NC) | Accessible in enclosure, USB ESD protected | Confirm physical service access |
| MCU-003 | Watchdog/reset | Put outputs into safe state on firmware lockup/reset | ESP32 watchdog plus external supervisor if needed | Hardware outputs must default safe | Decide if external supervisor is required |

## Power
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

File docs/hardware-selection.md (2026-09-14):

# Rev-A Hardware Selection

Updated 2026-09-14. This is the selected design, not a menu of interchangeable
parts. See the [capture register](schematic-capture-readiness.md) for components,
[sourcing matrix](jlcpcb-lcsc-sourcing.md) for order-time identifiers, and
[hardware dependencies](hardware-dependency-handoff.md) for qualification gates.

## Selected architecture

- ESP32-S3-WROOM-1U-N16R8 with external antenna, 16 MB flash and 8 MB octal PSRAM.
  GPIO35-37 are unavailable. Native USB is the programming path; J11 pins 3/4
  are NC, not a UART recovery interface.
- RAC10-12SK/277 isolated 12 V supply from protected AC input; R-78E5.0-0.5
  supplies 5 V and AP63203WU-7 supplies 3.3 V from 12 V.
- LM66100 ideal-diode paths isolate the two 5 V sources from backfeed.
  USB VBUS alone does not supply the separate 3.3 V regulator.
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

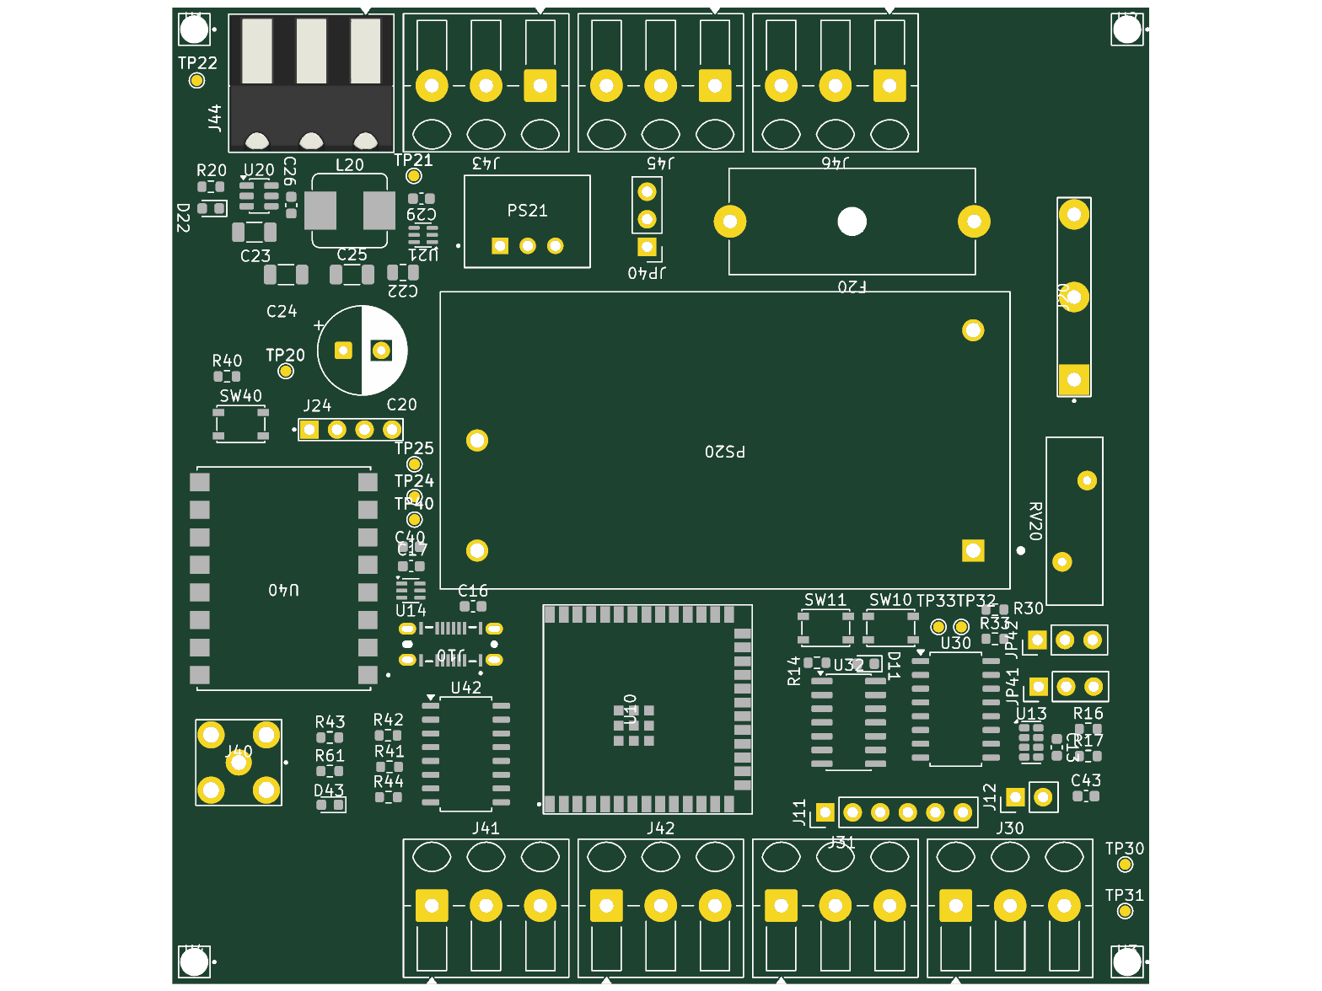
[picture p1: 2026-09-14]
docs/reviews/2026-09-13-pin-comms-fourlayer/board-top.png

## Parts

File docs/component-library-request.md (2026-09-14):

# Component library and source request list

This list has been reset to contain only parts whose final manufacturer library
assets are still useful. The schematic already uses KiCad or imported
SnapEDA assets for the ESP32, USB connector/protection, RECOM supplies, Linx RF
parts, VFD header, TXS0104E, TLP291 devices, AP63203, LM66100 and standard
passives.

September 13 hardware update: the optional AUX and MCU RUN circuits have been
removed; do not source U25 or the removed AUX parts for this revision. New R62
is a 1 kΩ 0603 resistor using standard KiCad assets, so no library download is
needed for this change. See the current hardware handoff for remaining D41
package verification and the revised pin mapping.

Do not install a downloaded footprint until its pin numbering, pad/drill geometry,
body outline and courtyard have been checked against the manufacturer drawing.

## Files still requested

| Priority | Exact part number | Files wanted | Why |
| --- | --- | --- | --- |
| High | `ED300/3` | KiCad/EasyEDA footprint and 3D model; symbol optional | This is the stocked 3-position, 5.00 mm field terminal used for encoder, switches and outputs. The schematic currently uses an Altech 5.00 mm provisional footprint. Manufacturer identity and exact body/drill dimensions are still needed. |
| High | Phoenix Contact `1717732` (`GMKDS 1,5/3-7,62`) | Manufacturer footprint/drawing and 3D model | Selected for the mains L/N/PE entry because its 7.62 mm pitch can support the project mains-clearance rule. A datasheet-derived provisional project footprint is installed; verify drill, body and courtyard before layout release. |
| High | `PM004MNIATR` | Manufacturer/EasyEDA symbol, SOP-8 footprint and 3D model | A datasheet-derived project-local symbol is already wired for the mandatory 4 Mbit MRAM. A downloaded asset is wanted as an independent pin-number and package check before PCB layout. |
| High | `LS7366R-S` | Manufacturer/EasyEDA symbol, SOIC-14 footprint and 3D model | A datasheet-derived project-local symbol is already wired. A downloaded asset is wanted as an independent pin-number/package check. |
| Medium | `RV-3028-C7` | Manufacturer footprint verification and 3D model | The RTC uses `Package_SON:MicroCrystal_C7_SON-8_1.5x3.2mm_P0.9mm`, not the earlier provisional LGA footprint. Verify the exact C7 drawing and model alignment. |

## Already imported or resolved

| Part number | Current project asset/status |
| --- | --- |
| `ESP32-S3-WROOM-1U-N16R8` | Imported SnapEDA symbol retained. The downloaded footprint's invalid 0.2 mm plated-hole array was replaced by project footprint `ESP32-S3-WROOM-1U-N16R8_CorrectedV2`; verify its exposed-pad segmentation during PCB review. |
| `USB4145-03-0230-C_REVA2` | Imported SnapEDA symbol and vertical GCT footprint; placed as the USB-C connector. |
| `TPD2EUSB30ADRTR` | Imported SnapEDA symbol/footprint at U12 on the USB data lines; verify the full suffix when sourcing. |
| `RAC10-12SK/277` | Imported SnapEDA symbol/footprint; exact part is placed on the power sheet. |
| `R-78E5.0-0.5` | Imported SnapEDA symbol/footprint; exact part is placed on the power sheet. |
| `RXM-418-LR` | Imported SnapEDA symbol/footprint; exact receiver is placed. |
| `LICAL-DEC-MS001` | Imported SnapEDA symbol and 20-SSOP footprint; exact decoder is placed. |
| `TSW-104-07-G-S` | Imported symbol retained; project footprint `SAMTEC_TSW-104-07-G-S_ZeroPadded` resolves the imported symbol's `01`-`04` numbering. |
| `TSW-106-07-G-S` | J11 boot/reset header uses the KiCad 1x06, 2.54 mm footprint; pins 3/4 are NC, not UART recovery. |
| `CONSMA002` | Project footprint `SMA_TE-Linx_CONSMA002_RightAngle` was created from the TE customer drawing and assigned to the 418 MHz Linx antenna input. A 3D model remains optional. |
| `AP63203WU-7` | Standard KiCad symbol and TSOT-23-6 footprint are sufficient. |
| `LM66100DCKR` | Standard KiCad symbol and SC-70-6 footprint are sufficient. |
| `TXS0104ED` | Standard KiCad symbol and SOIC-14 footprint are sufficient. |
| `TLP291` / `TLP291-4` | Standard KiCad symbols and Toshiba-compatible SOIC footprints are sufficient. |

D41 still specifies SMBJ15A with a D_SMA footprint; resolve the package mismatch
against the manufacturer drawing before ordering. Existing assets are not a
blanket package qualification.

## Selected real parts that do not need downloaded symbols

- Mains terminal: Phoenix Contact `1717732` (`GMKDS 1,5/3-7,62`); final downloaded mechanical asset is still requested above.
- Primary fuse holder: Schurter `0031.8201`, with a T500 mA 250 VAC 5 x 20 mm fuse.
- Mains MOV: Bourns `MOV-14D241K`.
- 3.3 V buck inductor: Bourns `SRP7028A-2R2M`, 2.2 uH. KiCad includes the exact series footprint.
- Protected 12 V distribution fuse: Bourns `MF-MSMF075/24X`, 0.75 A hold, 24 V, 1812 PPTC.
- USB-C CC resistors: Yageo `RC0603FR-075K1L`, 5.1 kOhm, 1%.

## Information to include with each download

- Exact manufacturer and full package suffix.
- Manufacturer datasheet or product drawing.
- KiCad/EasyEDA symbol and footprint files, plus 3D model when available.
- For connectors, a product photo and mating-part information.

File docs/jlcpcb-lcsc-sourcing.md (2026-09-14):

# Rev-A Sourcing References

Updated 2026-09-14. These are previously recorded catalogue identifiers for
selected parts, **not current stock, price or assembly-service guarantees**.
Recheck the exact suffix, package and assembly quote at order time. No
substitution is approved by this document.

| Block | Selected part | Recorded LCSC identifier | Qualification note |
| --- | --- | --- | --- |
| MCU | ESP32-S3-WROOM-1U-N16R8 | C3013946 | Corrected project footprint; external antenna variant |
| Counter | LS7366R-S | C3827808 | Confirm package and assembly availability |
| MRAM | PM004MNIATR | C5444277 | Confirm exact revision, package and interface mode |
| RTC | RV-3028-C7-32.768kHz-1ppm-TA-QC | C3019759 | Verify selected suffix against footprint |
| VFD translator | TXS0104ED | Recheck | Preserve field-matched UART topology |
| RF receiver | RXM-418-LR | C6670221 | Assembly or qualified harvested-part plan |
| RF decoder | LICAL-DEC-MS001 | Recheck | Exact 20-SSOP package; no transmitter IC required |
| AC/DC supply | RAC10-12SK/277 | C5199922 | Verify through-hole assembly and approvals |
| 3.3 V buck | AP63203WU-7 | C780769 | No automatic adjustable-variant substitution |
| Light MOSFET | AO3400A | C20917 | Check captured package, load/inrush and thermal margin |

The [capture register](schematic-capture-readiness.md) and exported design BOM
govern the remaining parts, including R-78E5.0-0.5, LM66100, TLP291-4,
74HC14D, connectors and protection. This is not a complete purchasing BOM.

## Before ordering

1. Export the current design BOM and reconcile exact manufacturer suffixes and
   quantities with the PCB, not an old candidate list.
2. Verify supplier stock, minimum quantities and assembly eligibility.
3. Check each footprint against the manufacturer drawing. Resolve D41's
   SMBJ15A/SMA mismatch and the open
   [component-library requests](component-library-request.md).
4. Complete power, mains isolation, enclosure and interface qualification gates.
   Do not order a production release from the unrouted board.

Unused alternate MCU/memory, optotriac, RS-485, industrial-input, UART-isolator
and AC/DC candidates have been removed from this working sourcing list.
Historical datasheets are retained as references only, not fitted parts.

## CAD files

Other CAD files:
hardware/SnapEDA-Library/ESP32-S3-WROOM-1U-N16R85.step
hardware/SnapEDA-Library/RAC10-12SK/2770.step
hardware/SnapEDA-Library/ESP32-S3-WROOM-1U-N16R83.step
hardware/SnapEDA-Library/R-78E5.0-0.50.step
hardware/SnapEDA-Library/ESP32-S3-WROOM-1U-N16R82.step
hardware/SnapEDA-Library/ESP32-S3-WROOM-1U-N16R80.step
hardware/SnapEDA-Library/ESP32-S3-WROOM-1U-N16R81.step
hardware/SnapEDA-Library/SMBJ15A0.step
hardware/SnapEDA-Library/ESP32-S3-WROOM-1U-N16R84.step
hardware/SnapEDA-Library/TPD2EUSB30ADRTR0.step
hardware/SnapEDA-Library/RC0603FR-075K1L0.step

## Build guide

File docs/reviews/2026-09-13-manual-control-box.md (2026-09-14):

# External manual-control box: hardware evidence review

Reviewed 2026-09-13. **Operational cargo profile not qualified.** This is an
evidence review, not permission to bypass a protection or operate the lift.
No KiCad design, firmware, interface contract, wiring, or safety protection was
changed. No equipment was energized, firmware uploaded, or physical motion requested.

## Finding and evidence boundary

September 14 documentation note: this is a dated evidence snapshot. Subsequent
software work adopted the owner-specified D0-D4 actions (Floor 1, Light, Floor 3,
Floor 2, STOP), a configurable diagnostic default of 9600, and target-bound
manual-release STOP. Its earlier instructions to keep baud=null describe the
reviewed revision, not current software. See the
[current handoff](../hardware-dependency-handoff.md). Physical RF mapping,
jumper compatibility and independent stopping/brake authority remain unverified.

The board and contract agree on the monitor and service inputs. However, the
repository evidence inspected does not include an as-wired external-box diagram,
contact schedule, independent stopping-chain trace, installed VFD configuration,
or brake-control circuit. Which contacts the override bypasses, which emergency
and final-limit protections remain effective, and what stops/holds the load are
**unknown**. The proposed override supplying a healthy monitor state is an owner
requirement, not a verified external circuit.

The board no longer contains the MCU RUN collector. That proves separation of
UART OE from the removed collector, **not** that serial RUN cannot bypass an
external stopping circuit. Neither cargo-only terminology nor a healthy GPIO
changes this evidence gap.

Evidence used:

- Fresh Konnect export: [current.net](2026-09-13-manual-control-box/current.net).
  Exact component/pin references below refer to this export, not an assumed cable.
- [Hardware change report](2026-09-13-pin-comms-fourlayer.md), its captured PCB
  pad evidence, and [firmware adoption report](2026-09-13-firmware-handoff.md).
- `firmware/interface-contract.json` v2, `firmware/include/PinMap.h`,
  `firmware/src/main.cpp:610`, `core/FieldInputs.h`, and `core/Supervisor.cpp:239`.
- `docs/new-controller-requirements.md`, Restricted Service Recovery;
  `docs/field-verification-log.md`, Safety/reference wiring;
  `README.md:230`, unanswered independent-safety-device inventory.
- `docs/vfd-serial-protocol.md` describes protocol capabilities, not actual
  drive parameter readback. `_old_resources/old_code.ino.txt:204` supports the
  historical LOW-healthy convention, but is not a wiring diagram for this box.
- Searches of repository documentation and resource filenames found no external
  box wiring evidence. Unprovided owner photos, cables, and installed equipment
  cannot be inspected through the project files.

## Verified controller-side connections

Every listed field input is a contact-to-board-GND input, not a 3.3 V external
logic input. The source path is +12 V through R41-R48 (2.2 kΩ), an optocoupler
LED, and the field contact to GND. R49-R56 (10 kΩ) pull the collectors to +3V3.
Thus sufficient LED current makes the MCU input LOW. Open field wiring makes it
HIGH when the 3.3 V supply and pull-up are intact. Nominal LED current is about
5 mA, calculated rather than measured; thresholds/current margin remain bench
items. Field and MCU returns share GND: these optocouplers do not establish an
independent galvanic safety barrier. Do not inject external 12/24 V into these
terminals based merely on the name of the safety signal.

| Input | Field terminal | LED cathode / collector | Pull-up | U10 module pad / GPIO |
| --- | --- | --- | --- | --- |
| SAFETY_MON | J41.1 | U42.2 / .16 | R49 | 39 / 1 |
| HOME | J41.2 | U42.4 / .14 | R50 | 38 / 2 |
| LIMIT_UP | J42.1 | U42.6 / .12 | R51 | 37 / 43, through R62 1 kΩ |
| LIMIT_DOWN | J42.2 | U42.8 / .10 | R52 | 36 / 44 |
| SERVICE_KEY | J43.1 | U43.2 / .16 | R53 | 15 / 3 |
| HOLD_TO_RUN | J43.2 | U43.4 / .14 | R54 | 31 / 38 |
| SERVICE_UP | J44.1 | U43.6 / .12 | R55 | 32 / 39 |
| SERVICE_DOWN | J44.2 | U43.8 / .10 | R56 | 33 / 40 |

J41/J42/J43/J44 pin 3 is GND. GPIO35/36/37 remain unavailable on the
ESP32-S3-WROOM-1U-N16R8. GPIO3 reset/eFuse qualification and GPIO43 ROM UART
contention remain the bench gates described in the hardware change report.

## Mode and input truth tables

L/H are measured-at-MCU logic levels, not field-terminal voltage. X means
unknown/unqualified. Rows assume a healthy 3.3 V rail/pull-up and enough field
current where stated. None is a physical motion-permission certification.

| Electrical condition | MCU input | Meaning / ambiguity |
| --- | --- | --- |
| Powered field contact closed to GND | L | Asserted; SAFETY_MON is interpreted healthy |
| Contact open | H | Deasserted; SAFETY_MON interpreted non-healthy |
| Broken signal or return conductor | H, absent another current path | Indistinguishable from an open contact |
| +12 V absent, +3V3 intact | H | Indistinguishable from open inputs; no dedicated field-power proof |
| Signal shorted to GND | L with field power | Can imitate healthy safety, active key, or pressed button |
| MCU supply missing/reset/boot or input circuitry faulty | X | Do not infer a valid software state or a physical stop |

| Proposed physical mode/event | SAFETY_MON | KEY / HOLD / UP / DOWN | What can be concluded |
| --- | --- | --- | --- |
| Ordinary healthy loop | L by proposed interface | Actual wiring unknown; expected inactive contacts would read H | Healthy monitor alone does not prove ordinary mode |
| Keyed override intentionally enabled | L by proposed interface | KEY=L only if a separate key contact is actually wired/closed at J43.1 | Same safety bit as ordinary healthy operation |
| Healthy monitor plus service up request | L | L / L / L / H, conditional on contact wiring | Core service-request pattern, not proof of external override or permission |
| Healthy monitor plus service down request | L | L / L / H / L, conditional | Same limitation |
| Key released | May remain L for an ordinary healthy loop | KEY=H if its contact opens | Core service stop request; hardwired effect unknown |
| Hold released | Not established by board | HOLD=H if its contact opens | Core service stop request; hardwired effect unknown |
| Both directions pressed | Not established by board | UP=L and DOWN=L | Core rejects service start / requests service stop; external arbitration unknown |
| Safety loop opens without an asserted override | H if monitor contact opens | Other inputs depend on wiring | Software non-healthy, but independent stop mechanism unverified |
| Override remains enabled while a bypassed contact opens | L is possible under proposal | No bypass identity or feedback input exists | Cannot discover which protection was bypassed from these bits |

Existing independent SERVICE_KEY input could identify a key position **only after**
an auxiliary contact, its mechanical relationship to the override, and its truth
table are documented. It does not prove that bypass contacts actually transferred
or reveal which devices remain effective. A stuck/shorted key input also appears
active. Do not derive override mode from SAFETY_MON, hold, or direction alone.

### NO/NC consequences that must not be conflated

- An NC healthy safety-monitor contact opening on fault is consistent with
  LOW=healthy and open-wire=non-healthy, provided there is no parallel bypass.
- A NO limit contact closing at travel end matches current LOW=limit-active
  software, but a broken wire resembles a clear limit.
- An NC limit contact opening at travel end gives the reverse mechanical meaning
  from current LOW=limit-active software. It cannot be silently adopted as compatible.
- Key/hold/direction NO closures would match current active-low assertions, but
  the installed contact arrangements are not evidenced. Home is likewise unresolved.

Retain the current polarity and qualification inhibit. Resolve the field truth
table before proposing a software inversion or hardware change.

## Independent stopping authority: established versus missing

```text
ESTABLISHED controller paths
J41-J44 contacts -> U42/U43 conditioning -> MCU GPIO -> software decisions
MCU UART17/18 <-> U24 translator <-> J24 <-> external VFD serial port
GPIO42 -> U24.8 OE + R24 pulldown ONLY (communications, not RUN permission)

UNVERIFIED installation path -- not an as-built circuit
E-stop / final limits / other protections / key and hold contacts
    -> [unknown bypass topology and relay/contact arrangement]
    -> [unknown independent VFD inhibit or energy-interruption mechanism]
    -> motor torque removal / stopping / brake application / load holding
```

R25/U25/J25/TP26 are absent. J24 is 01=5V, 02=GND, 03=VFD RX,
04=VFD TX; no hardwired RUN signal is present there. No trace in this board's
export puts J41-J44 contacts into an independent drive/brake interruption chain.
The required separate installation circuit could exist; it is not proven here.
Do not assume an EM01 terminal is STO, that loss of torque applies a brake, or
that a brake is spring-applied merely because a brake is mentioned in requirements.

| Failure/event | Software evidence | Independent physical outcome still needed |
| --- | --- | --- |
| Key/hold release; direction release/conflict | `Supervisor.cpp:286` and :296 request stop in service; release-to-arm at :225; service timeout 5 s | Contact interruption path and stopping/holding action without MCU |
| Broken safety wire | Normally HIGH/non-healthy; :243 faults when hardware is qualified | Does the break also interrupt independent authority? Parallel paths? |
| Broken limit/home wire | HIGH can resemble inactive/clear under current convention | NO/NC schedule, separate final limit, continuity diagnosis |
| Loss of field power | Collectors tend HIGH if 3V3 survives | Relay dropout, brake supply/default, restart behavior; no inference from GPIO |
| MCU crash/reset/unpowered | Code cannot guarantee STOP during a crash; OE pulldown disables UART on reset when effective | Hardware response with MCU absent; retained VFD command and brake behavior |
| UART loss | Core faults on communication loss; diagnostics cannot establish physical stop | Installed timeout/action, independent stop path, brake timing, restart latch |
| Serial RUN while external stop asserted | Present diagnostics profile does not send RUN | Drive configuration/topology must make RUN ineffective independently of software |
| Welded/bypassed contact or short-to-GND monitor | May still read healthy | Independent detection/protection and reset conditions, not debounce |

`main.cpp:72` leaves FieldContinuityQualified=false; contract deploymentReady is
false. Therefore service motion is presently inhibited even with the hypothetical
valid patterns above. Core stop behavior is host-tested logic, not operational
drive control or a safety-rated stopping function. Safety/home/hold/direction are
sampled directly; the 100 ms stability/25 ms freshness filter in FieldInputs.h
applies to upper/lower/key and must not be described as filtering all eight inputs.

## RF evidence and remaining assembly decisions

Fresh export: JP41.2 -> U41.3 SEL_BAUD0; JP42.2 -> U41.4 SEL_BAUD1.
Both jumpers have pin 1=GND and pin 3=3V3. Each is a three-pin both-open symbol;
no center-net pull resistor or recorded assembly shunt selection establishes a default.

| JP42 BAUD1 shunt | JP41 BAUD0 shunt | Baud |
| --- | --- | --- |
| 1-2 (LOW) | 1-2 (LOW) | 2400 |
| 1-2 (LOW) | 2-3 (HIGH) | 9600 |
| 2-3 (HIGH) | 1-2 (LOW) | 19200 |
| 2-3 (HIGH) | 2-3 (HIGH) | 28800 |

This is the component's selection table, **not a selected build configuration**.
Set before power-up and match the existing transmitter. TX_ID uses the selected
baud; U41.7 LATCH is GND, specifying momentary active-HIGH data outputs, unlike
the optocoupled active-LOW field inputs. Source: Linx-authored
[MS decoder data guide, Figure 9 and Latch/TX ID sections](https://www.mouser.com/datasheet/2/238/lical-dec-ms001-1109236.pdf).
Its safety warning also means this RF link must not be credited as an independent
emergency stopping system. Receiver/transmitter rate compatibility still requires
qualification; listing all decoder rates does not endorse all rates for this RF path.

| Decoder output/pin | MCU GPIO / module pad | Physical button assignment |
| --- | --- | --- |
| D0 / U41.13 | 4 / 4 | Unknown |
| D1 / U41.14 | 5 / 5 | Unknown |
| D2 / U41.17 | 6 / 6 | Unknown |
| D3 / U41.18 | 7 / 7 | Unknown |
| D4 / U41.19 | 8 / 12 | Unknown |

Floor 1/2/3, Stop and Light are intended functions, not an evidenced D0-D4 order.
Legacy Serial1/Serial2 at 9600 (`old_code.ino.txt:71`) does not prove the decoder
straps or remote-button mapping. Keep contract baud=null and
buttonMappingVerified=false. Do not learn/erase remotes to answer this review.

## Owner evidence needed and non-energized verification plan

Obtain the following without operating the lift. Any enclosure access or electrical
measurement requires qualified personnel and the site's energy-control procedure,
including stored electrical/mechanical energy and a secured gravity load. A key,
STOP button, software inhibit, or disconnected MCU is not energy isolation.
See [OSHA energy-control guidance](https://www.osha.gov/etools/lockout-tagout/hot-topics/energy-control-program/energy-control-circuitry-prohibition).
This review does not authorize energization to collect missing data.

| ID | Prerequisite and procedure | Required record / acceptance evidence |
| --- | --- | --- |
| MB-01 topology | Existing drawings first; qualified de-energized trace if absent | Terminal-to-terminal drawing covering every key pole, hold/direction contact, E-stop, gate/latch/safety device, ordinary and final limits, relay coils/contacts, VFD inputs and brake supply. Mark every bypass branch explicitly. Label normal and override current paths. |
| MB-02 identification | Safe access under site isolation procedure | Overall and close-up photos of box front/back, every switch contact block/terminal number and wire marker, both cable ends, relay/safety-controller part numbers, VFD exact model/revision/terminal labels, motor/brake nameplates and any brake rectifier/controller. Photos must show hidden key poles, not just the front legend. |
| MB-03 contact schedule | Isolated and verified de-energized contacts; disconnect from electronics only under a documented qualified procedure, label/restoration controlled | Record continuity/resistance and actual terminal pairs for key normal/override, hold released/held, up/down released/pressed/both, each E-stop and each limit independently actuated without carriage travel. Identify NO/NC/COM and mechanical linkage. Parallel connected circuits can invalidate a simple continuity reading. |
| MB-04 monitor harness | De-energized, identified harness and return | Trace J41-J44 destinations and common. Establish whether outputs are dry contacts or driven signals, rated source voltage/current, and whether key has an independent auxiliary contact. Document simulated open conductor effects by circuit analysis/isolated continuity, not a live wire-break experiment. |
| MB-05 drive and brake authority | Existing parameter backup/manuals and complete MB-01 | Exact terminal function and command-source configuration, serial timeout/action, reset/auto-restart behavior, brake voltage/default state and controlling contacts. For every E-stop/final limit, trace how it stops/holds with override engaged and MCU absent. Manufacturer evidence must resolve serial RUN precedence; no RUN trial in this review. |
| RF-01 straps | Batteries removed; board/remote isolated from all supplies | Photos of decoder and every existing remote board; continuity of SEL_BAUD0/1 to supply/ground with pin-1 orientation recorded; identify transmitter/encoder variants. Record new-board shunt assembly instruction only after confirming compatibility. |
| RF-02 button mapping | Remotes unpowered/batteries removed | Label each physical button and trace its encoder data input using photos/isolated continuity. Relate that data line to decoder D0-D4, including any unconnected D5-D7. If traces cannot be established, leave unknown pending a separately authorized isolated RF bench test with no lift connected. Do not press a powered remote near the installation. |

Non-energized inspection can establish topology and contact states, not dropout
time, braking distance/holding capacity, relay fault response under power, or
serial-command precedence in the actual drive. Those remain separate qualified,
supervised bench/system verification gates after an approved safety architecture.
No powered procedure was run or authorized here.

## Checks performed and handoff

- Konnect fresh root netlist export succeeded; IO short-net scan: 0.
- Konnect root ERC at **error severity**: 0 errors. This does not mean zero warnings;
  the earlier warning-inclusive report recorded 31 warnings, not requalified here.
- Konnect PCB DRC: 325 unconnected items, 181 warnings, zero schematic parity
  findings; total 325 errors. Full [DRC JSON](2026-09-13-manual-control-box/drc.json)
  retained. No new routing or physical integration claimed.
- Existing read-only netlist checker: 227 assertions PASS against fresh export and
  previously captured IPC pads. This is not a fresh live-PCB IPC capture.
- `node firmware/scripts/generate-contract.mjs --check`: PASS.
- `node firmware/tests/contract.mjs`: PASS v2 inhibited contract.
- `firmware/tests/run.ps1`: PASS 2866 assertions, **host simulation only**.
- Three saved schematic file hashes (MCU, VFD, IO) differ from the older hardware
  report's hash manifest. The fresh exported connectivity passes; do not describe
  that old manifest as the current source snapshot. PCB/project hashes match it.

No hardware readiness claim is closed by these software/connectivity checks.
The prior hardware report's statement that firmware updates remain mandatory is
historical: v2 software adoption is now evidenced. Conversely, the contract field
`motionAuthority=external-hardwired-safety-loop-only-no-mcu-run-permission-output`
is an intended architecture plus a verified absent board output, not proof of an
installed independent chain. README's fail-safe stop/brake requirement remains
unfulfilled evidence, not an implemented controller brake output.

Firmware handoff: preserve diagnostic-only v2, deployment/upload/motion inhibits,
active-low field convention, unavailable GPIO35-37, and GPIO42 translator-only
behavior. Do not substitute a healthy monitor bit, cargo-only label, or host-test
result for MB-01 through MB-05. Keep HW-03/HW-05 and new HW-11 open. Any future
operational profile needs an explicitly reviewed mode/authority contract based on
the owner evidence above; do not silently reinterpret SERVICE_KEY as verified
override feedback or invert NC limits. No software changes are requested by this
evidence review alone.

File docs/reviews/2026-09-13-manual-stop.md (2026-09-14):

# Manual Switch Release To STOP

This is a partial implementation milestone, not the requested operational v3 release.
Contract v2, finalized GPIO mapping, SAFETY_MON LOW=healthy, and motion/upload
inhibits remain. No KiCad edits, controller connection, upload, commit or push occurred.

## Implemented

- Target raw manual-input sampling precedes UART, HTTP, SPI and logging each loop.
- Startup, key takeover/removal, hold release, direction change/loss/conflict,
  safety loss, invalid input and >25 ms sampling gaps queue EM01 STOP operation 3
  using the existing checksum implementation. There is no release debounce delay.
- STOP preempts the pending diagnostic transaction. Repeated STOP requests coalesce
  while STOP is pending, preserving the three-attempt timeout instead of restarting
  it continuously. STOP remains available after a communication timeout.
- Stop transmission is serviced before the corresponding durable manual event is
  written. Event results say queued, not physically stopped. Existing faults are
  not cleared. A stalled loop or unavailable UART still prevents immediate delivery;
  this is software ordering, not a qualified hard-real-time stopping guarantee.
- Web floor calls are rejected while the manual key is asserted or manual input
  levels are unknown. Input intent appears in API/WebUI separately from motion
  permission; no manual RUN binding is enabled.
- The isolated RF normal-mode model now maps D0 floor 1, D1 light toggle, D2 floor 3,
  D3 floor 2, D4 STOP. Learned-slot/association-epoch checks and duplicate suppression
  remain. Default configurable diagnostic baud is 9600; decoder jumper/UART rate
  matching is distinct from RF remote timing. No target RF UART was started.

## Tests Executed

| Command | Local result |
| --- | --- |
| `npm ci` | Pass; 21 audit findings remain |
| `npm run check` | Pass |
| `npm run lint` | Pass |
| `npm test` | 12 tests pass |
| `npx playwright install --with-deps chromium` | Pass |
| `npm run test:browser` | Pass; 1440x1000 and 390x844, mocked API |
| `npm run build:embedded` | Pass; 236,179 raw / 71,491 gzip bytes |
| `node scripts/stage-firmware.mjs` | Pass |
| `pio run` | Pass; 48,832 RAM bytes, 845,805 flash bytes |
| `pio run -t buildfs` | Pass; no upload |
| `node firmware/scripts/generate-contract.mjs --check` | Pass |
| `node firmware/tests/contract.mjs` | Pass, including manual STOP ordering checks |
| `./firmware/tests/run.ps1` | 3,223 assertions pass |
| `python firmware/tests/test_build_guard.py` | Pass; fake build environment only |

Tests cover all 32 binary key/hold/up/down/safety input combinations, request
removal and STOP on release, conflicting/unknown inputs, sample gaps, monitor
preemption, repeated STOP requests, retry exhaustion, STOP after timeout, RF normal
map/duplicate behavior, and API rejection of contradictory manual intent. Browser
tests retain failed STOP, accepted STOP without physical-stop claims, disconnect/
reconnect, malformed status and responsive overflow checks. Physical switch timing,
UART delivery and actual mechanical stopping were not tested. Ubuntu CI was not run.

## Changed Files

- `firmware/src/core/ManualStop.h` (new)
- `firmware/src/core/DiagnosticVfd.h`
- `firmware/src/core/Rf.h`
- `firmware/src/main.cpp`
- `firmware/interface-contract.json` (RF specification metadata only; still v2)
- `firmware/tests/core_tests.cpp`
- `firmware/tests/contract.mjs`
- `firmware/README.md`
- `webapp/lib/controller.ts`
- `webapp/app/page.tsx`
- `webapp/tests/fixtures/status.json`
- `webapp/tests/controller.test.mjs`
- `webapp/tests/browser.mjs`
- `webapp/docs/api-contract.md`
- `webapp/README.md`
- `webapp/docs/embedded-delivery.md`
- `README.md`
- `docs/hardware-dependency-handoff.md`
- `docs/software-integration-checklist.md`
- `docs/webapp-embedded-delivery.md`
- This report.

Ignored build, manifest and screenshot outputs were regenerated.

## Outstanding Larger Request

Operational v3 activation, target RUN/write binding, target RF capture/learning,
RF programming D4 floor capture, WebUI programming/calibration, direction-specific
calibration persistence/predictive stopping, and full motion/response audit coverage
are not completed by this milestone. Existing host-only components are not a claim
that those target workflows work. The supplied EM01 operation definitions are not
a missing-frame blocker for this STOP implementation; no alternative frames were
invented. Echo/late-response behavior and parameter 13 readback remain bench/protocol
qualification concerns recorded in the prior handoff.

The physical external box and means of holding/stopping the load on controller,
drive or power failure remain unverified. This milestone implements the requested
serial STOP behavior; it does not establish independent stopping authority or
remove protections based on that behavior.

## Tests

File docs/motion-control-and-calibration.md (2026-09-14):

# Motion Control And Calibration

## Recommended Motion Strategy

Retain measured deceleration-distance stopping: command a selected VFD speed and
issue STOP early by a measured offset. The owner reported good legacy accuracy;
that observation does not qualify this controller or establish the old fault's cause.

Do not use a classic PID position loop as the primary lift control strategy. The VFD already controls motor speed and ramp behavior, and the controller talks to it through a relatively slow serial command path. A PID loop would add tuning complexity without solving the main historic risk, which was likely state/position/serial robustness rather than poor steady-state positioning.

## Current Firmware Behavior

The portable supervisor uses a directional prediction-stop threshold:

```text
remaining_counts = (target_counts - position_counts) * direction
remaining_counts <= measured_stop_distance -> request STOP
```

This is implemented in `firmware/src/core/Supervisor.cpp`, with separate overshoot,
progress, wrong-direction and final-tolerance checks. `core/Configuration` serializes
the measured calibration metadata into versioned MRAM journal records. Target
commissioning and program-exit APIs are still unsupported while hardware is
inhibited; see the software integration checklist. No floor positions or valid
calibration are invented at startup.

## Calibration Mode Requirement

The requested operational profile preserves measured coast distance, but starts
calibration explicitly rather than automatically on programming-mode exit:

1. User enters programming/calibration mode from the WebUI or service workflow.
2. User sets or confirms floor positions.
3. Start calibration explicitly from the WebUI after validating Floor 1 < Floor 2 < Floor 3. At or below the Floor 1/Floor 3 midpoint choose upward travel; above it choose downward travel. Reject insufficient travel before RUN.
4. The controller commands motion long enough to reach the configured normal run speed.
5. The controller records the position at the instant it sends the stop command.
6. The controller waits for fresh VFD stopped-status/zero-frequency telemetry and stable encoder position. STOP acknowledgement alone is never sufficient.
7. The controller records the final stopped position.
8. The measured difference becomes the deceleration travel distance.
9. The controller stores the calibration value in MRAM with sequence number and CRC.

This calibration value is mostly determined by the VFD deceleration-rate parameter. If the WebUI changes VFD deceleration or normal run speed, the controller should mark the stop calibration stale and require recalibration before normal unattended motion.

## Stored Calibration Data

The current isolated model stores one calibration. The requested operational
profile requires separate upward/downward offsets; the single-record model is
not complete. For each direction retain:

- `configuration_revision`
- `calibrated_run_speed_tenths_hz`
- `calibrated_vfd_decel_parameter`
- `calibration_direction`
- `start_position_counts`
- `stop_command_position_counts`
- `final_position_counts`
- `measured_stop_distance_counts`
- `timestamp_or_sequence`
- `crc`

Normal floor travel must reject absent, stale or direction-mismatched calibration.
Changes to floors, encoder scaling, speed, deceleration or relevant drive parameters
invalidate it. Explicit-start and directional persistence remain integration work.

## Runtime Checks

Keep the runtime logic conservative:

- Stop command is sent when remaining distance is less than or equal to the calibrated offset.
- Repeat STOP independently of bounded reply retries; see [EM01 timing](vfd-serial-protocol.md). Neither acknowledgement nor retry exhaustion proves physical stopping.
- If final stopped position is outside an allowed tolerance, latch a fault or require service recalibration.
- Relevant settings changes invalidate calibration; a warning alone must not permit normal motion.
- Calibration mode must not override hardwired safety devices, final limits, or fault conditions.

## Top Reference And Service Boundary

There are exactly three floors, increasing in the upward direction. HOME is a
separate configured reference near floor 3, not floor-one zero. A rising HOME
event during upward homing records the reference crossing; coast after that edge
is retained. The counter-origin adapter must complete the reference handshake
before position becomes valid. An already-active HOME cannot establish a new
reference without a deliberate service approach. Ordinary idle HOME never
changes coordinates. Homing/calibration require local key plus continuous hold;
service release requests STOP and cancels completion. All constants require field
commissioning and physical verification before an operational profile exists.

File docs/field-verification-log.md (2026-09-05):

# Field Verification Log

This log separates observed legacy hardware from design decisions for the new
controller. An observed implementation is useful evidence, but it is not an
automatic approval for the new safety or production design.

## 2026-08-30 Site Inspection Notes

| Area | Observation | Design impact | Status |
| --- | --- | --- | --- |
| PCB envelope | Legacy board is approximately 90 mm x 90 mm. Corner mounting-hole centers are 86 mm apart in both axes, placing their centers approximately 2 mm from each board edge. | Rev-A board outline target is 90 mm x 90 mm. Keep the existing 86 mm square mounting pattern. | Measured/estimated; verify with calipers before fabrication release. |
| Mounting clearance | About 40 mm of enclosure height is available in most areas. The underside needs about 12 mm clearance at the mounting screws. | Keep tall parts away from the standoff/screw keepouts; record exact screw head and standoff dimensions before mechanical release. | Estimated. |
| Mount holes | Hole diameter was described as approximately 2.56 mm. | Treat 2.56 mm as a provisional hole diameter only; select the finished-hole size after identifying the screw size and measuring a hole directly. | Unconfirmed. |
| Legacy controller | Particle Xenon, Linx RF receiver/transceiver hardware, and encode/decode hardware are fitted on headers. Spare legacy boards are available for possible harvesting. | Provide a documented legacy-RF interface option. Harvested parts require electrical, functional, and mechanical inspection before use; do not make them the sole sourcing path for production. | Observed. |
| RF learn access | The decoder `LEARN` signal is not present on its header and is routed to a physical button. The legacy installation uses a soldered wire from that board to the main PCB. | Provide a dedicated `RF_LEARN` interface pad/header and safe-default MCU control. Retain a local physical Learn button or service pads. | Observed. |
| VFD serial connector | A four-pin male header, likely 2.54 mm pitch, carries VFD RX/TX through a TI `TXS0104E`; no discrete transistor or series resistor is used on this path. | The Rev-A circuit has been cross-checked against this field topology and includes a defined OE pull-down and test pads. Verify the assembled board and connector before lift connection. | Electrical topology confirmed against field design; connector pitch, pin order, levels, and assembled-board behavior remain bench gates. |
| Legacy power | An accessory I/O board supplies 24 VDC through Ethernet-style cabling. The legacy controller uses a RECOM `R-78E5.0-0.5` non-isolated 24 V-to-5 V regulator. | The captured combined board takes protected 120 VAC + neutral into `RAC10-12SK/277`, then uses the same R-78E family from 12 V to 5 V and AP63203 from 12 V to 3.3 V. | Legacy input observed; new 12 V-fed converter arrangement selected for Rev A. |
| Encoder | Four-wire encoder wiring appears to use 12 V supply. A/B are pulled up to 12 V through 270 ohm resistors, then pass through 270 ohm series resistors into a `TLP291-4` optocoupler. An additional optocoupler and an HC74 flip-flop are visible but their function is unknown. | Reproduce the electrical behavior only after measuring encoder current, A/B polarity, pulse rate, and optocoupler outputs. The new design must provide protected isolated/translated logic compatible with the LS7366R counter. | Part markings and resistor values observed; signal routing unconfirmed. |
| Safety/reference wiring | The safety-loop wire and HOME limit switch are intended to terminate at the new controller. | Include both as monitored inputs while preserving independent hardwired safety authority. | Requirement confirmed; voltage, contact type, and chain topology remain open. |
| EMI/shielding | No deliberate shielding or ground plane was evident on the legacy PCB. | Rev A must add ground planes, separation of mains/VFD/encoder/RF regions, surge/ESD protection, and a chassis/shield plan. | Observed. |

## Evidence Still Required Before Schematic Release

1. Measure the VFD four-pin header pinout, common/reference, idle voltage, and cable length with the drive powered and disconnected from the controller as appropriate.
2. Verify the assembled field-matched `TXS0104E` stage, connector pinout, levels, and fault behavior on a bench fixture before connecting a new controller to the lift.
3. Measure encoder supply, A/B high/low voltage, low-state current, pulse rate at maximum speed, cable length, and shield termination. Trace the outputs of the `TLP291-4` and HC74.
4. Identify the safety-loop and HOME switch voltage, contact topology, and which motion authority remains hardwired when the MCU is unpowered.
5. Confirm the AC tap, neutral, protective-earth connection, disconnect relationship, fuse location, and wire gauge.
6. Measure the light load voltage, steady current, inrush, connector, and return path before sizing the 12 V supply and output switch.
7. Measure actual mounting-hole diameter and screw/standoff dimensions.

## Referenced Datasheets

- `TI_TXS0104E_level_translator_datasheet.pdf` — local copy; 3.3 V/5 V auto-direction translator reference.
- `RECOM_R-78E5.0-0.5_5V_regulator_datasheet.pdf` — local copy; selected Rev-A 12 V-to-5 V regulator, with legacy 24 V use retained as historical evidence.
- Toshiba `TLP291-4` official datasheet — local download pending because Toshiba's server rejected automated retrieval.
- TE/Linx `LICAL-DEC-MS001` official datasheet — local download pending because TE's server rejected automated retrieval.

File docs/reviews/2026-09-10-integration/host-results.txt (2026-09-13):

CONFIRMED protocol documented stop/monitor vectors
CONFIRMED protocol 45Hz forward vector
CONFIRMED DEFECT acknowledgement accepts unframed substring
CONFIRMED DEFECT fresh empty NVS boots idle at invented zero
CONFIRMED DEFECT boot writes four drive parameters without initial STOP or ACK
CONFIRMED DEFECT no encoder pulses or VFD replies for one hour still requests run
CONFIRMED DEFECT overshot stop window continues forward
CONFIRMED DEFECT stale stop ACK marks new stop idle
CONFIRMED DEFECT STOP then ACK bypasses fault latch without explicit reset
CONFIRMED safety-open request rejected and STOP emitted
CONFIRMED forward active upper limit faults under provisional GPIO mapping
CONFIRMED missing stop ACK timeout faults
CONFIRMED DEFECT fault state stops STOP retrying
CONFIRMED DEFECT top HOME resets coordinate to floor-one zero
CONFIRMED DEFECT accepted stored stopping offset not used by motion
CONFIRMED DEFECT settings update changes commanded speed during movement
CONFIRMED DEFECT invalid floor258 wraps to floor2
CONFIRMED DEFECT partially numeric command accepted
CONFIRMED DEFECT parameter266 wraps to FMAX10
CONFIRMED parameter write blocked while moving
CONFIRMED DEFECT unauthenticated parameter read sends UART during motion without arbiter
CONFIRMED configured token rejects unauthorized writes
CONFIRMED DEFECT reboot accepted while moving without STOP
CONFIRMED DEFECT main loop restarts with active run state
CONFIRMED DEFECT UI light endpoint absent
CONFIRMED DEFECT unsupported advertised setting fields silently ignored
CONFIRMED position persistence round-trip in simulated Preferences
CONFIRMED position CRC rejects corrupted simulated blob
CONFIRMED DEFECT periodic persistence failure not surfaced as fault
CONFIRMED log retention is32 RAM events despite2048 setting
CONFIRMED DEFECT initial high button interpreted as new command
CONFIRMED DEFECT network SSID emitted without JSON escaping
CONFIRMED DEFECT conflicting limits not rejected at command acceptance
CONFIRMED DEFECT unexpected idle movement not detected
CONFIRMED DEFECT simultaneous floor buttons silently choose code-order winner
CONFIRMED DEFECT safety-open boot writes drive parameters but never sends STOP
CONFIRMED additional original EM01 manual transmit vectors
STATUS_JSON {"state":"moving","position":12000,"target":40000,"targetFloor":3,"normalRunTenthsHz":450,"safetyOk":true,"home":false,"lowerLimit":false,"upperLimit":false,"lastVfdCommand":"","lastFault":"","networkMode":"fallback_ap","stationIp":"","apIp":""}
Checks=37 unexpected=0

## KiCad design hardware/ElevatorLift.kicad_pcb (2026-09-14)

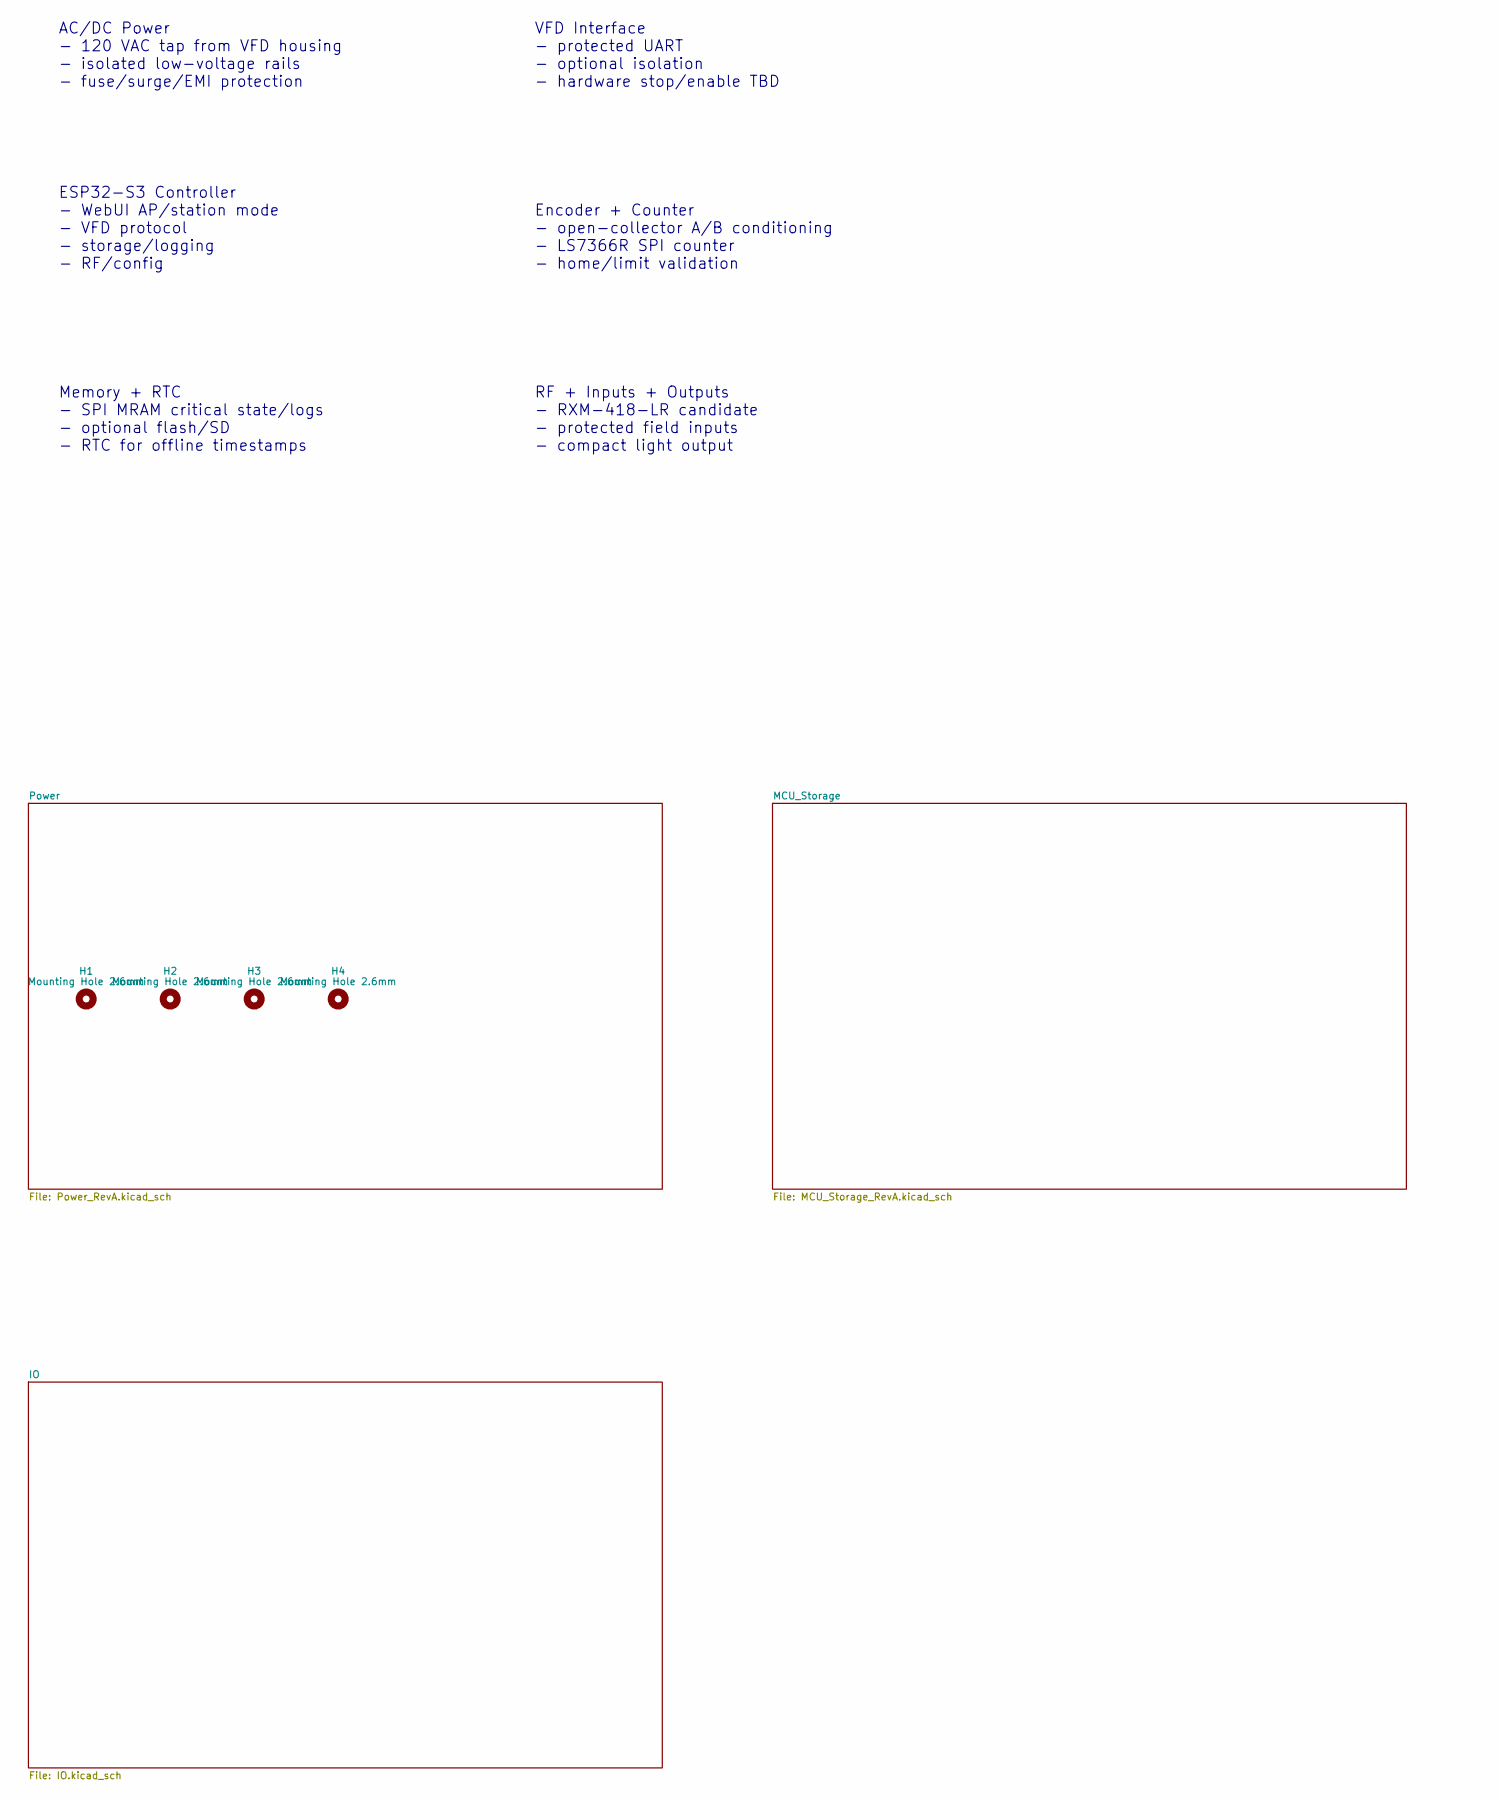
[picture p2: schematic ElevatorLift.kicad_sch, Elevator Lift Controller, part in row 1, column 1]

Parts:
H1, H2, H3, H4: Mounting Hole 2.6mm; MountingHole_2.6mm_NPTH

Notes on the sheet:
ESP32-S3 Controller - WebUI AP/station mode - VFD protocol - storage/logging - RF/config
RF + Inputs + Outputs - RXM-418-LR candidate - protected field inputs - compact light output
AC/DC Power - 120 VAC tap from VFD housing - isolated low-voltage rails - fuse/surge/EMI protection
VFD Interface - protected UART - optional isolation - hardware stop/enable TBD
Memory + RTC - SPI MRAM critical state/logs - optional flash/SD - RTC for offline timestamps
Encoder + Counter - open-collector A/B conditioning - LS7366R SPI counter - home/limit validation

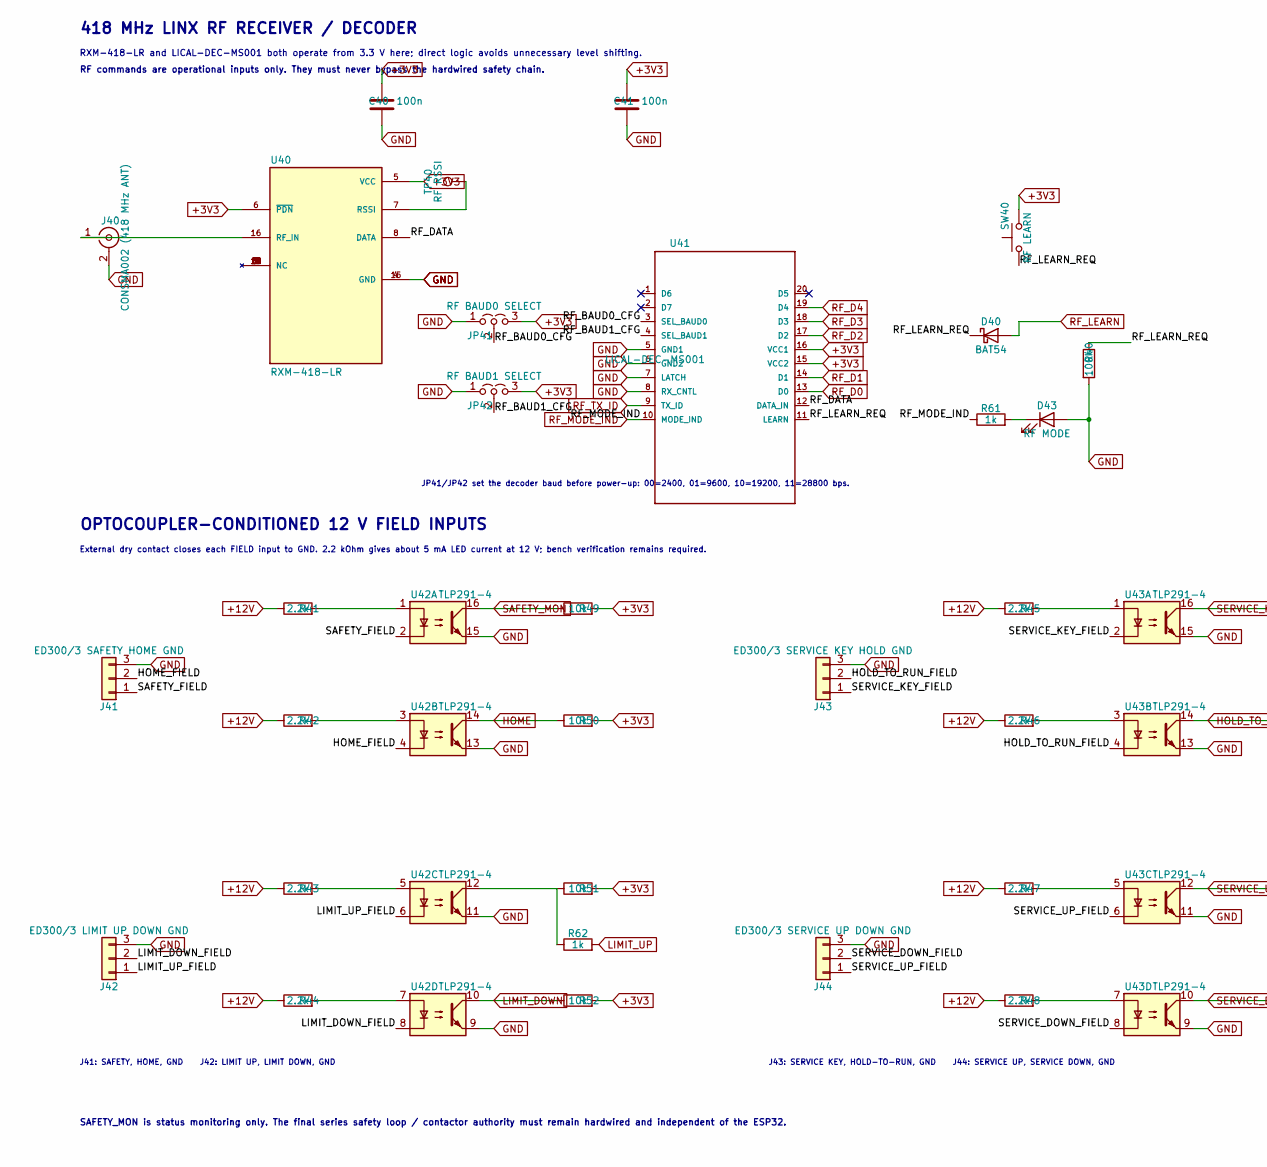
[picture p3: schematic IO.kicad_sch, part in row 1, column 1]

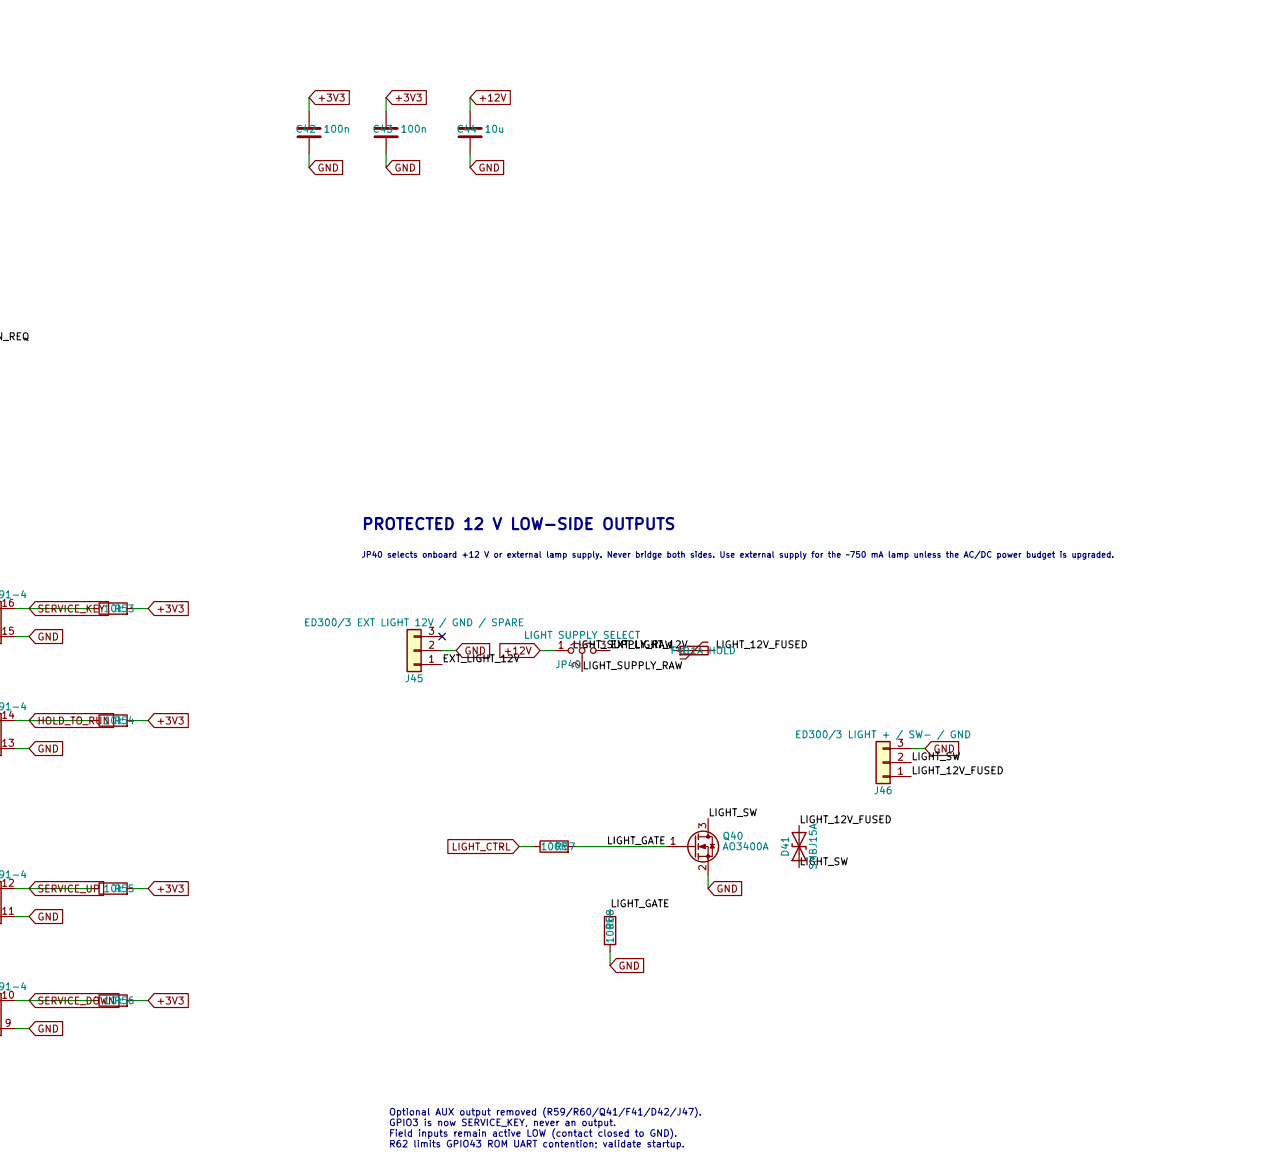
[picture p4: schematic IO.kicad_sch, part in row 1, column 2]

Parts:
C40, C41, C42, C43: 100n; C_0603_1608Metric
C44: 10u; C_0805_2012Metric
D40: BAT54; D_SOD-323
D41: SMBJ15A; D_SMA
D43: RF MODE; LED_0603_1608Metric
F40: 1.1A HOLD; Fuse_1812_4532Metric
J40: CONSMA002 (418 MHz ANT); SMA_TE-Linx_CONSMA002_RightAngle
J41: ED300/3 SAFETY HOME GND; Altech_AK300_1x03_P5.00mm_45-Degree
J42: ED300/3 LIMIT UP DOWN GND; Altech_AK300_1x03_P5.00mm_45-Degree
J43: ED300/3 SERVICE KEY HOLD GND; Altech_AK300_1x03_P5.00mm_45-Degree
J44: ED300/3 SERVICE UP DOWN GND; Altech_AK300_1x03_P5.00mm_45-Degree
J45: ED300/3 EXT LIGHT 12V / GND / SPARE; Altech_AK300_1x03_P5.00mm_45-Degree
J46: ED300/3 LIGHT + / SW- / GND; Altech_AK300_1x03_P5.00mm_45-Degree
JP40: LIGHT SUPPLY SELECT; PinHeader_1x03_P2.54mm_Vertical
JP41: RF BAUD0 SELECT; PinHeader_1x03_P2.54mm_Vertical
JP42: RF BAUD1 SELECT; PinHeader_1x03_P2.54mm_Vertical
Q40: AO3400A; SOT-23
R40, R58: 100k; R_0603_1608Metric
R41, R42, R43, R44, R45, R46, R47, R48: 2.2k; R_0603_1608Metric
R49, R50, R51, R52, R53, R54, R55, R56: 10k; R_0603_1608Metric
R57: 100R; R_0603_1608Metric
R61, R62: 1k; R_0603_1608Metric
SW40: RF LEARN; SW_SPST_PTS810
TP40: RF RSSI; TestPoint_Pad_D1.0mm
U40: RXM-418-LR; XCVR_RXM-418-LR; MPN RXM-418-LR
U41: LICAL-DEC-MS001; 20-SSOP; MPN LICAL-DEC-MS001
U42, U43: TLP291-4; SOIC-16_4.55x10.3mm_P1.27mm; MPN TLP291-4

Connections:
+3V3: C40.1, C41.1, C42.1, C43.1, JP41.3 (B), JP42.3 (B), R49.2, R50.2, R51.2, R52.2, R53.2, R54.2, R55.2, R56.2, SW40.2, U40.5 (VCC), U40.6 (~PDN), U41.15 (VCC2), U41.16 (VCC1); also elsewhere on the board
+12V: C44.1, JP40.1 (A), R41.1, R42.1, R43.1, R44.1, R45.1, R46.1, R47.1, R48.1; also elsewhere on the board
/IO/EXT_LIGHT_12V: J45.1, JP40.3 (B)
/IO/HOLD_TO_RUN_FIELD: J43.2, U43.4
/IO/HOME_FIELD: J41.2, U42.4
/IO/LIGHT_12V_FUSED: D41.2 (A2), F40.2, J46.1
/IO/LIGHT_GATE: Q40.1 (G), R57.2, R58.1
/IO/LIGHT_SUPPLY_RAW: F40.1, JP40.2 (C)
/IO/LIGHT_SW: D41.1 (A1), J46.2, Q40.3 (D)
/IO/LIMIT_DOWN_FIELD: J42.2, U42.8
/IO/LIMIT_UP_FIELD: J42.1, U42.6
/IO/RF_BAUD0_CFG: JP41.2 (C), U41.3 (SEL_BAUD0)
/IO/RF_BAUD1_CFG: JP42.2 (C), U41.4 (SEL_BAUD1)
/IO/RF_DATA: U40.8 (DATA), U41.12 (DATA_IN)
/IO/RF_LEARN_REQ: D40.1 (K), R40.1, SW40.1, U41.11 (LEARN)
/IO/SAFETY_FIELD: J41.1, U42.2
/IO/SERVICE_DOWN_FIELD: J44.2, U43.8
/IO/SERVICE_KEY_FIELD: J43.1, U43.2
/IO/SERVICE_UP_FIELD: J44.1, U43.6
GND: C40.2, C41.2, C42.2, C43.2, C44.2, D43.2 (A), J40.2 (Ext), J41.3, J42.3, J43.3, J44.3, J45.2, J46.3, JP41.1 (A), JP42.1 (A), Q40.2 (S), R40.2, R58.2, U40.4 (GND), U40.15 (GND), U41.5 (GND1), U41.6 (GND2), U41.7 (LATCH), U41.8 (RX_CNTL), U42.9, U42.11, U42.13, U42.15, U43.9, U43.11, U43.13, U43.15; also elsewhere on the board
HOLD_TO_RUN: R54.1, U43.14; also elsewhere on the board
HOME: R50.1, U42.14; also elsewhere on the board
LIGHT_CTRL: R57.1; also elsewhere on the board
LIMIT_DOWN: R52.1, U42.10; also elsewhere on the board
LIMIT_UP: R62.2; also elsewhere on the board
unnamed: D43.1 (K), R61.2
unnamed: J40.1 (In), U40.16 (RF_IN)
unnamed: R41.2, U42.1
unnamed: R42.2, U42.3
unnamed: R43.2, U42.5
unnamed: R44.2, U42.7
unnamed: R45.2, U43.1
unnamed: R46.2, U43.3
unnamed: R47.2, U43.5
unnamed: R48.2, U43.7
unnamed: R51.1, R62.1, U42.12
unnamed: TP40.1 (1_1), U40.7 (RSSI)
RF_D0: U41.13 (D0); also elsewhere on the board
RF_D1: U41.14 (D1); also elsewhere on the board
RF_D2: U41.17 (D2); also elsewhere on the board
RF_D3: U41.18 (D3); also elsewhere on the board
RF_D4: U41.19 (D4); also elsewhere on the board
RF_LEARN: D40.2 (A); also elsewhere on the board
RF_MODE_IND: R61.1, U41.10 (MODE_IND); also elsewhere on the board
RF_TX_ID: U41.9 (TX_ID); also elsewhere on the board
SAFETY_MON: R49.1, U42.16; also elsewhere on the board
SERVICE_DOWN: R56.1, U43.10; also elsewhere on the board
SERVICE_KEY: R53.1, U43.16; also elsewhere on the board
SERVICE_UP: R55.1, U43.12; also elsewhere on the board

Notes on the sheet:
418 MHz LINX RF RECEIVER / DECODER
J43: SERVICE KEY, HOLD-TO-RUN, GND J44: SERVICE UP, SERVICE DOWN, GND
OPTOCOUPLER-CONDITIONED 12 V FIELD INPUTS
PROTECTED 12 V LOW-SIDE OUTPUTS
RF commands are operational inputs only. They must never bypass the hardwired safety chain.
External dry contact closes each FIELD input to GND. 2.2 kOhm gives about 5 mA LED current at 12 V; bench verification remains required.
JP40 selects onboard +12 V or external lamp supply. Never bridge both sides. Use external supply for the ~750 mA lamp unless the AC/DC power budget is upgraded.
SAFETY_MON is status monitoring only. The final series safety loop / contactor authority must remain hardwired and independent of the ESP32.
JP41/JP42 set the decoder baud before power-up: 00=2400, 01=9600, 10=19200, 11=28800 bps.
Optional AUX output removed (R59/R60/Q41/F41/D42/J47). GPIO3 is now SERVICE_KEY, never an output. Field inputs remain active LOW (contact closed to GND). R62 limits GPIO43 ROM UART contention; validate startup.
RXM-418-LR and LICAL-DEC-MS001 both operate from 3.3 V here; direct logic avoids unnecessary level shifting.
J41: SAFETY, HOME, GND J42: LIMIT UP, LIMIT DOWN, GND

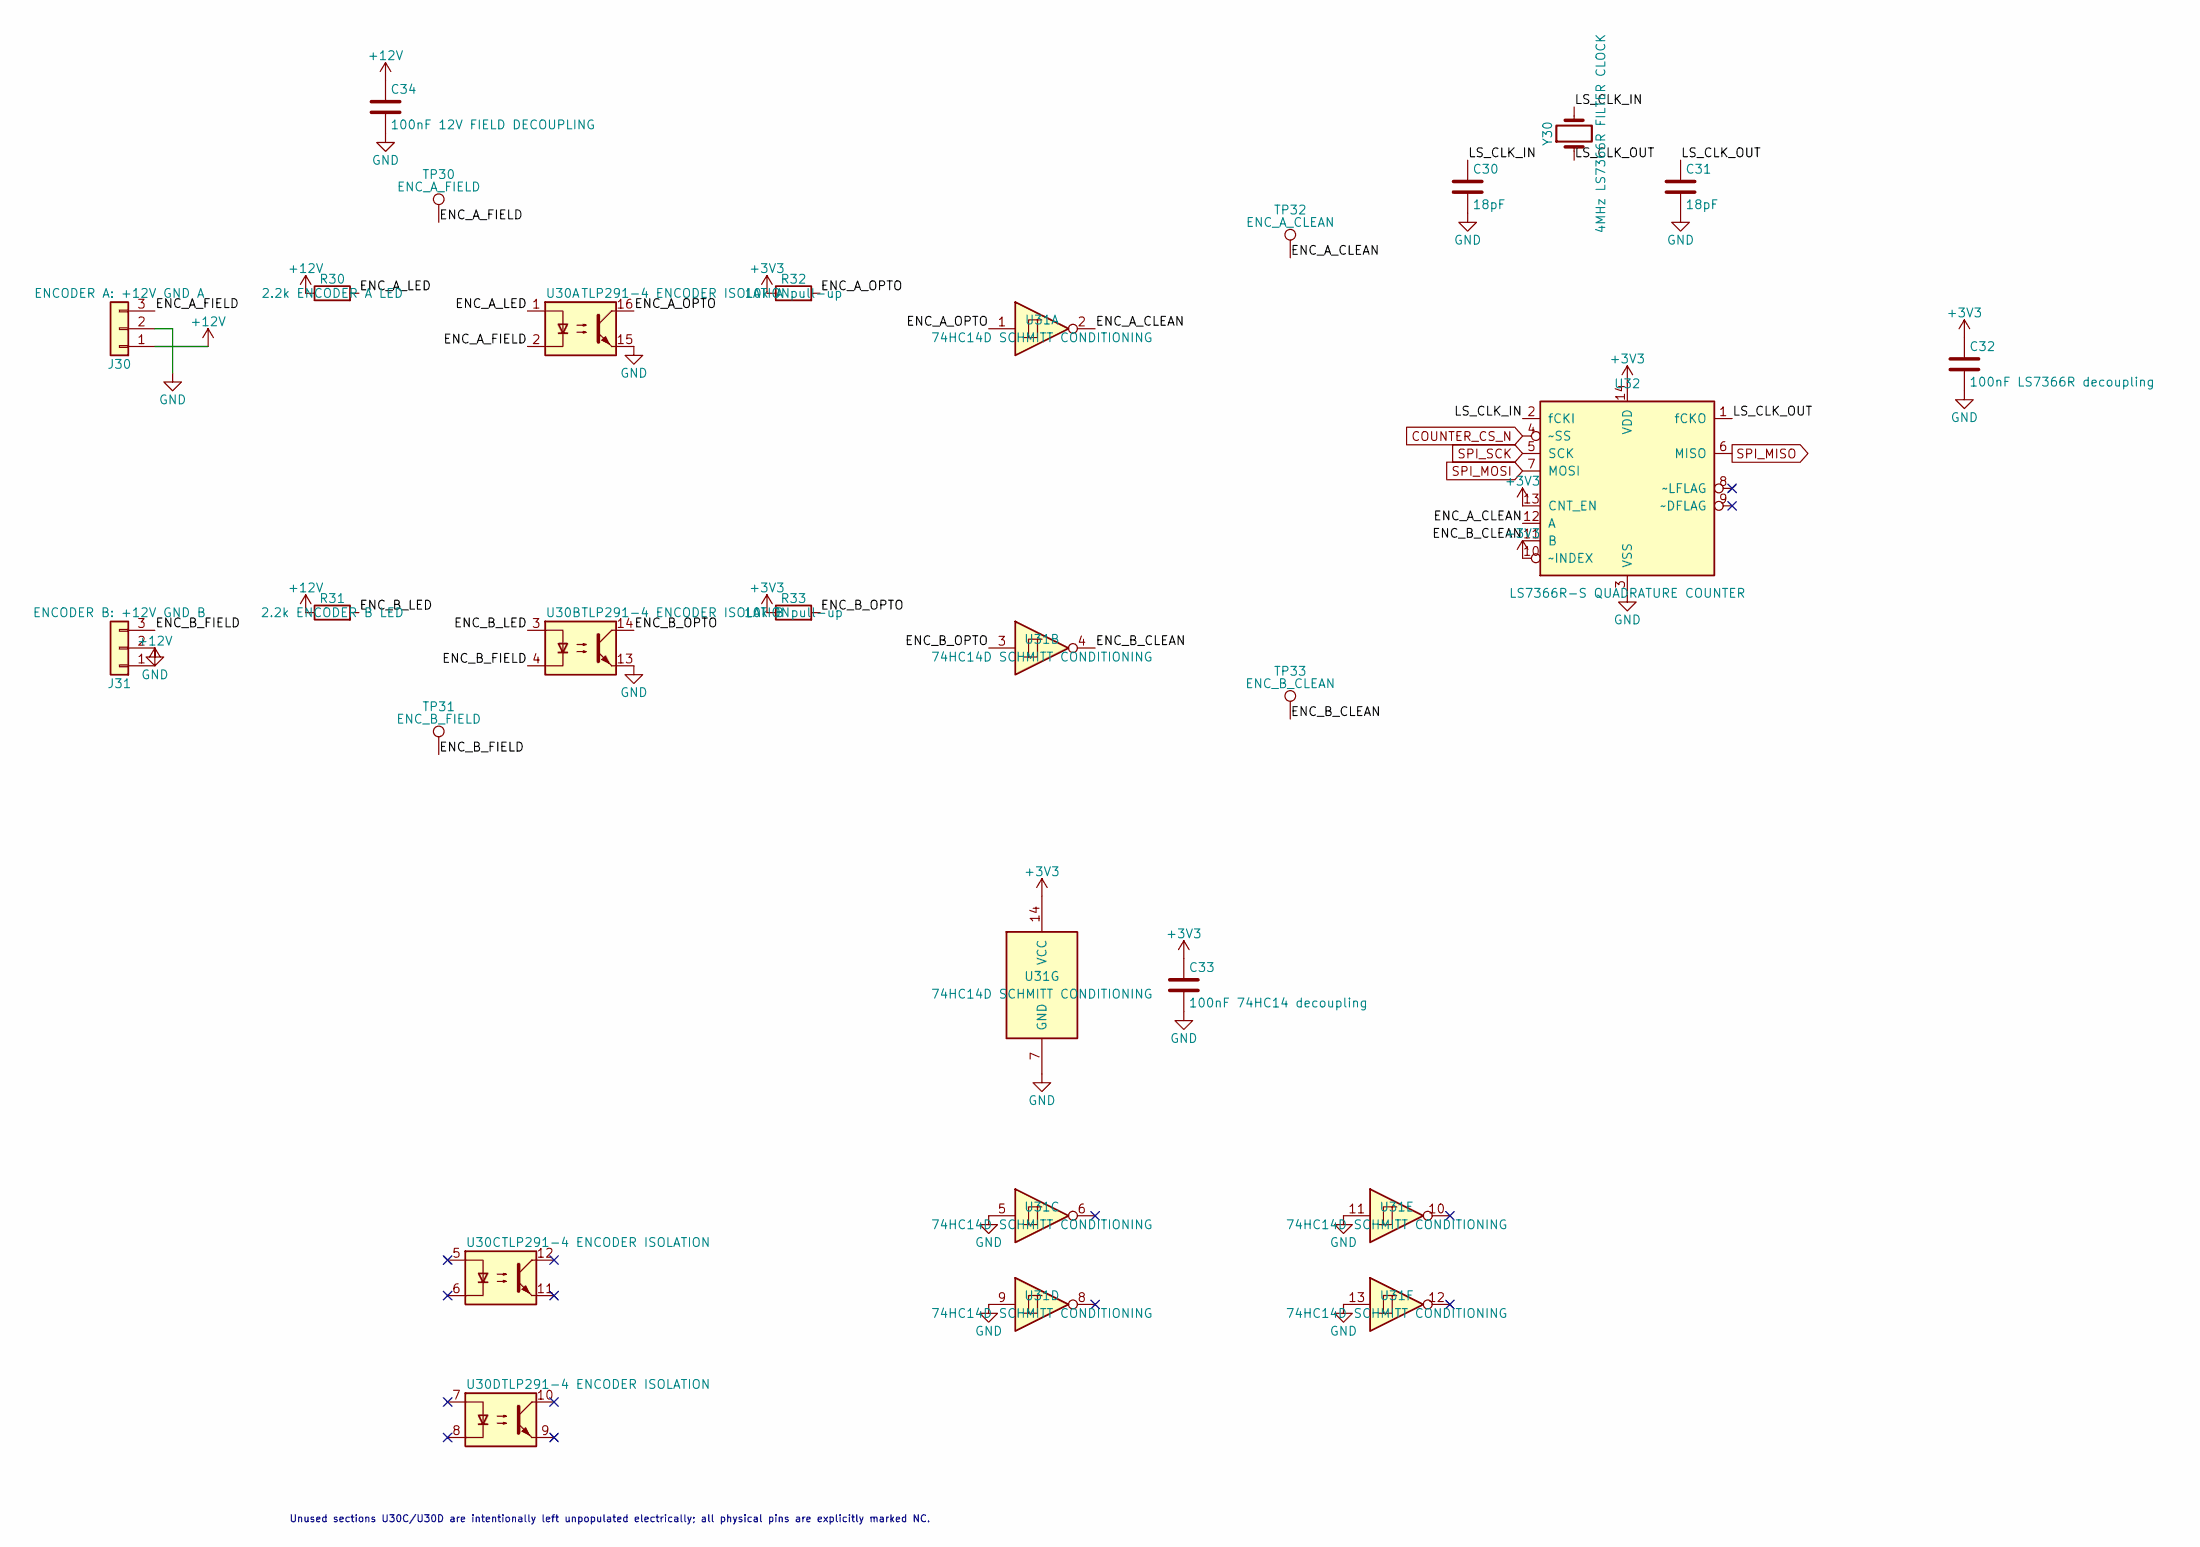
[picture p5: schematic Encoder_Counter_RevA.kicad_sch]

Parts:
C30, C31: 18pF; C_0603_1608Metric
C32: 100nF LS7366R decoupling; C_0603_1608Metric
C33: 100nF 74HC14 decoupling; C_0603_1608Metric
C34: 100nF 12V FIELD DECOUPLING; C_0603_1608Metric
J30: ENCODER A: +12V GND A; Altech_AK300_1x03_P5.00mm_45-Degree
J31: ENCODER B: +12V GND B; Altech_AK300_1x03_P5.00mm_45-Degree
R30: 2.2k ENCODER A LED; R_0603_1608Metric
R31: 2.2k ENCODER B LED; R_0603_1608Metric
R32: 10k A pull-up; R_0603_1608Metric
R33: 10k B pull-up; R_0603_1608Metric
TP30: ENC_A_FIELD; TestPoint_Pad_D1.0mm
TP31: ENC_B_FIELD; TestPoint_Pad_D1.0mm
TP32: ENC_A_CLEAN; TestPoint_Pad_D1.0mm
TP33: ENC_B_CLEAN; TestPoint_Pad_D1.0mm
U30: TLP291-4 ENCODER ISOLATION; SOIC-16_4.55x10.3mm_P1.27mm; MPN TLP291-4
U31: 74HC14D SCHMITT CONDITIONING; SOIC-14_3.9x8.7mm_P1.27mm; MPN 74HC14D,653
U32: LS7366R-S QUADRATURE COUNTER; SOIC-14_3.9x8.7mm_P1.27mm; MPN LS7366R-S
Y30: 4MHz LS7366R FILTER CLOCK; Crystal_SMD_3225-4Pin_3.2x2.5mm

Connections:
+3V3: C32.1, C33.1, R32.1, R33.1, U31.14 (VCC), U32.10 (~INDEX), U32.13 (CNT_EN), U32.14 (VDD); also elsewhere on the board
+12V: C34.1, J30.1, J31.1, R30.1, R31.1; also elsewhere on the board
/Encoder_Counter/ENC_A_CLEAN: TP32.1 (1_1), U31.2, U32.12 (A)
/Encoder_Counter/ENC_A_FIELD: J30.3, TP30.1 (1_1), U30.2
/Encoder_Counter/ENC_A_LED: R30.2, U30.1
/Encoder_Counter/ENC_A_OPTO: R32.2, U30.16, U31.1
/Encoder_Counter/ENC_B_CLEAN: TP33.1 (1_1), U31.4, U32.11 (B)
/Encoder_Counter/ENC_B_FIELD: J31.3, TP31.1 (1_1), U30.4
/Encoder_Counter/ENC_B_LED: R31.2, U30.3
/Encoder_Counter/ENC_B_OPTO: R33.2, U30.14, U31.3
/Encoder_Counter/LS_CLK_IN: C30.1, U32.2 (fCKI), Y30.2
/Encoder_Counter/LS_CLK_OUT: C31.1, U32.1 (fCKO), Y30.1
COUNTER_CS_N: U32.4 (~SS); also elsewhere on the board
GND: C30.2, C31.2, C32.2, C33.2, C34.2, J30.2, J31.2, U30.13, U30.15, U31.5, U31.7 (GND), U31.9, U31.11, U31.13, U32.3 (VSS); also elsewhere on the board
SPI_MISO: U32.6 (MISO); also elsewhere on the board
SPI_MOSI: U32.7 (MOSI); also elsewhere on the board
SPI_SCK: U32.5 (SCK); also elsewhere on the board

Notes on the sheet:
Unused sections U30C/U30D are intentionally left unpopulated electrically; all physical pins are explicitly marked NC.

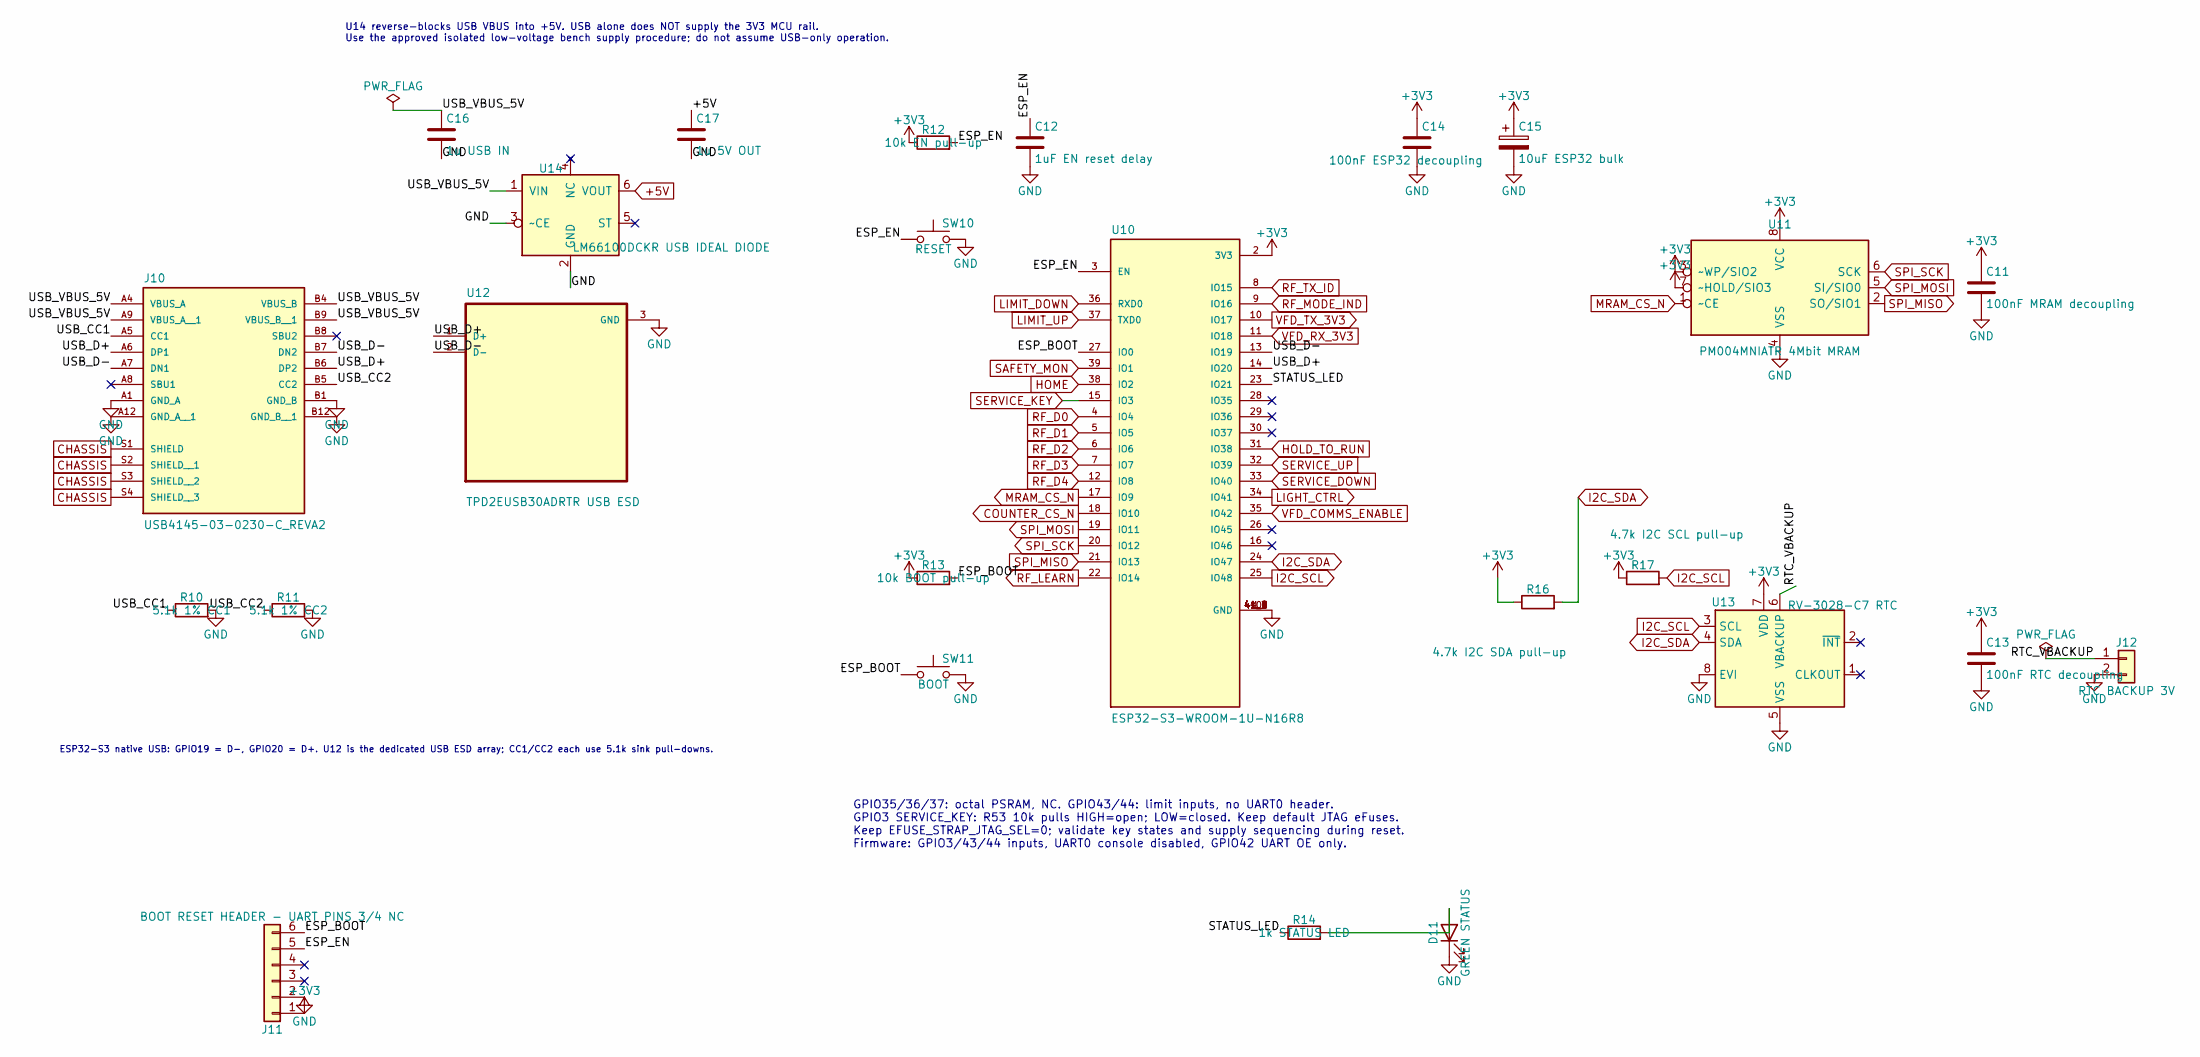
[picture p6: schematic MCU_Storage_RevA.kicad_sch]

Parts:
C11: 100nF MRAM decoupling; C_0603_1608Metric
C12: 1uF EN reset delay; C_0603_1608Metric
C13: 100nF RTC decoupling; C_0603_1608Metric
C14: 100nF ESP32 decoupling; C_0603_1608Metric
C15: 10uF ESP32 bulk; C_0805_2012Metric
C16: 1u USB IN; C_0603_1608Metric
C17: 1u 5V OUT; C_0603_1608Metric
D11: GREEN STATUS; LED_0603_1608Metric
J10: USB4145-03-0230-C_REVA2; GCT_USB4145-03-0230-C_REVA2
J11: BOOT RESET HEADER - UART PINS 3/4 NC; PinHeader_1x06_P2.54mm_Vertical
J12: RTC BACKUP 3V; PinHeader_1x02_P2.54mm_Vertical
R10: 5.1k 1% CC1; R_0603_1608Metric
R11: 5.1k 1% CC2; R_0603_1608Metric
R12: 10k EN pull-up; R_0603_1608Metric
R13: 10k BOOT pull-up; R_0603_1608Metric
R14: 1k STATUS LED; R_0603_1608Metric
R16: 4.7k I2C SDA pull-up; R_0603_1608Metric
R17: 4.7k I2C SCL pull-up; R_0603_1608Metric
SW10: RESET; SW_SPST_PTS810
SW11: BOOT; SW_SPST_PTS810
U10: ESP32-S3-WROOM-1U-N16R8; ESP32-S3-WROOM-1U-N16R8_CorrectedV2; MPN ESP32-S3-WROOM-1U-N16R8
U11: PM004MNIATR 4Mbit MRAM; SOIC-8_3.9x4.9mm_P1.27mm; MPN PM004MNIATR
U12: TPD2EUSB30ADRTR USB ESD; SOTFL35P100X50-3N; MPN TPD2EUSB30ADRTR
U13: RV-3028-C7 RTC; MicroCrystal_C7_SON-8_1.5x3.2mm_P0.9mm; MPN RV-3028-C7
U14: LM66100DCKR USB IDEAL DIODE; SOT-363_SC-70-6; MPN LM66100DCKR

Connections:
+3V3: C11.1, C13.1, C14.1, C15.1, J11.1, R12.1, R13.1, R16.1, R17.1, U10.2 (3V3), U11.3 (~WP/SIO2), U11.7 (~HOLD/SIO3), U11.8 (VCC), U13.7 (VDD); also elsewhere on the board
+5V: C17.1, U14.6 (VOUT); also elsewhere on the board
/MCU_Storage/ESP_BOOT: J11.6, R13.2, SW11.1, U10.27 (IO0)
/MCU_Storage/ESP_EN: C12.1, J11.5, R12.2, SW10.1, U10.3 (EN)
/MCU_Storage/RTC_VBACKUP: J12.1, U13.6 (VBACKUP)
/MCU_Storage/STATUS_LED: R14.1, U10.23 (IO21)
/MCU_Storage/USB_CC1: J10.A5 (CC1), R10.1
/MCU_Storage/USB_CC2: J10.B5 (CC2), R11.1
/MCU_Storage/USB_D+: J10.A6 (DP1), J10.B6 (DP2), U10.14 (IO20), U12.1 (D+)
/MCU_Storage/USB_D-: J10.A7 (DN1), J10.B7 (DN2), U10.13 (IO19), U12.2 (D-)
/MCU_Storage/USB_VBUS_5V: C16.1, J10.A4 (VBUS_A), J10.A9 (VBUS_A__1), J10.B4 (VBUS_B), J10.B9 (VBUS_B__1), U14.1 (VIN)
CHASSIS: J10.S1 (SHIELD), J10.S2 (SHIELD__1), J10.S3 (SHIELD__2), J10.S4 (SHIELD__3); also elsewhere on the board
COUNTER_CS_N: U10.18 (IO10); also elsewhere on the board
GND: C11.2, C12.2, C13.2, C14.2, C15.2, C16.2, C17.2, D11.1 (K), J10.A1 (GND_A), J10.A12 (GND_A__1), J10.B1 (GND_B), J10.B12 (GND_B__1), J11.2, J12.2, R10.2, R11.2, SW10.2, SW11.2, U10.1 (GND), U10.40 (GND), U10.41_1 (GND), U10.41_2 (GND), U10.41_3 (GND), U10.41_4 (GND), U10.41_5 (GND), U10.41_6 (GND), U10.41_7 (GND), U10.41_8 (GND), U10.41_9 (GND), U11.4 (VSS), U12.3 (GND), U13.5 (VSS), U13.8 (EVI), U14.2 (GND), U14.3 (~CE); also elsewhere on the board
HOLD_TO_RUN: U10.31 (IO38); also elsewhere on the board
HOME: U10.38 (IO2); also elsewhere on the board
I2C_SCL: R17.2, U10.25 (IO48), U13.3 (SCL)
I2C_SDA: R16.2, U10.24 (IO47), U13.4 (SDA)
LIGHT_CTRL: U10.34 (IO41); also elsewhere on the board
LIMIT_DOWN: U10.36 (RXD0); also elsewhere on the board
LIMIT_UP: U10.37 (TXD0); also elsewhere on the board
MRAM_CS_N: U10.17 (IO9), U11.1 (~CE)
unnamed: D11.2 (A), R14.2
RF_D0: U10.4 (IO4); also elsewhere on the board
RF_D1: U10.5 (IO5); also elsewhere on the board
RF_D2: U10.6 (IO6); also elsewhere on the board
RF_D3: U10.7 (IO7); also elsewhere on the board
RF_D4: U10.12 (IO8); also elsewhere on the board
RF_LEARN: U10.22 (IO14); also elsewhere on the board
RF_MODE_IND: U10.9 (IO16); also elsewhere on the board
RF_TX_ID: U10.8 (IO15); also elsewhere on the board
SAFETY_MON: U10.39 (IO1); also elsewhere on the board
SERVICE_DOWN: U10.33 (IO40); also elsewhere on the board
SERVICE_KEY: U10.15 (IO3); also elsewhere on the board
SERVICE_UP: U10.32 (IO39); also elsewhere on the board
SPI_MISO: U10.21 (IO13), U11.2 (SO/SIO1); also elsewhere on the board
SPI_MOSI: U10.19 (IO11), U11.5 (SI/SIO0); also elsewhere on the board
SPI_SCK: U10.20 (IO12), U11.6 (SCK); also elsewhere on the board
VFD_COMMS_ENABLE: U10.35 (IO42); also elsewhere on the board
VFD_RX_3V3: U10.11 (IO18); also elsewhere on the board
VFD_TX_3V3: U10.10 (IO17); also elsewhere on the board

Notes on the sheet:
GPIO35/36/37: octal PSRAM, NC. GPIO43/44: limit inputs, no UART0 header. GPIO3 SERVICE_KEY: R53 10k pulls HIGH=open; LOW=closed. Keep default JTAG eFuses. Keep EFUSE_STRAP_JTAG_SEL=0; validate key states and supply sequencing during reset. Firmware: GPIO3/43/44 inputs, UART0 console disabled, GPIO4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
U14 reverse-blocks USB VBUS into +5V. USB alone does NOT supply the 3V3 MCU rail. Use the approved isolated low-voltage bench supply procedure; do not assume USB-only operation.
ESP32-S3 native USB: GPIO19 = D-, GPIO20 = D+. U12 is the dedicated USB ESD array; CC1/CC2 each use 5.1k sink pull-downs.

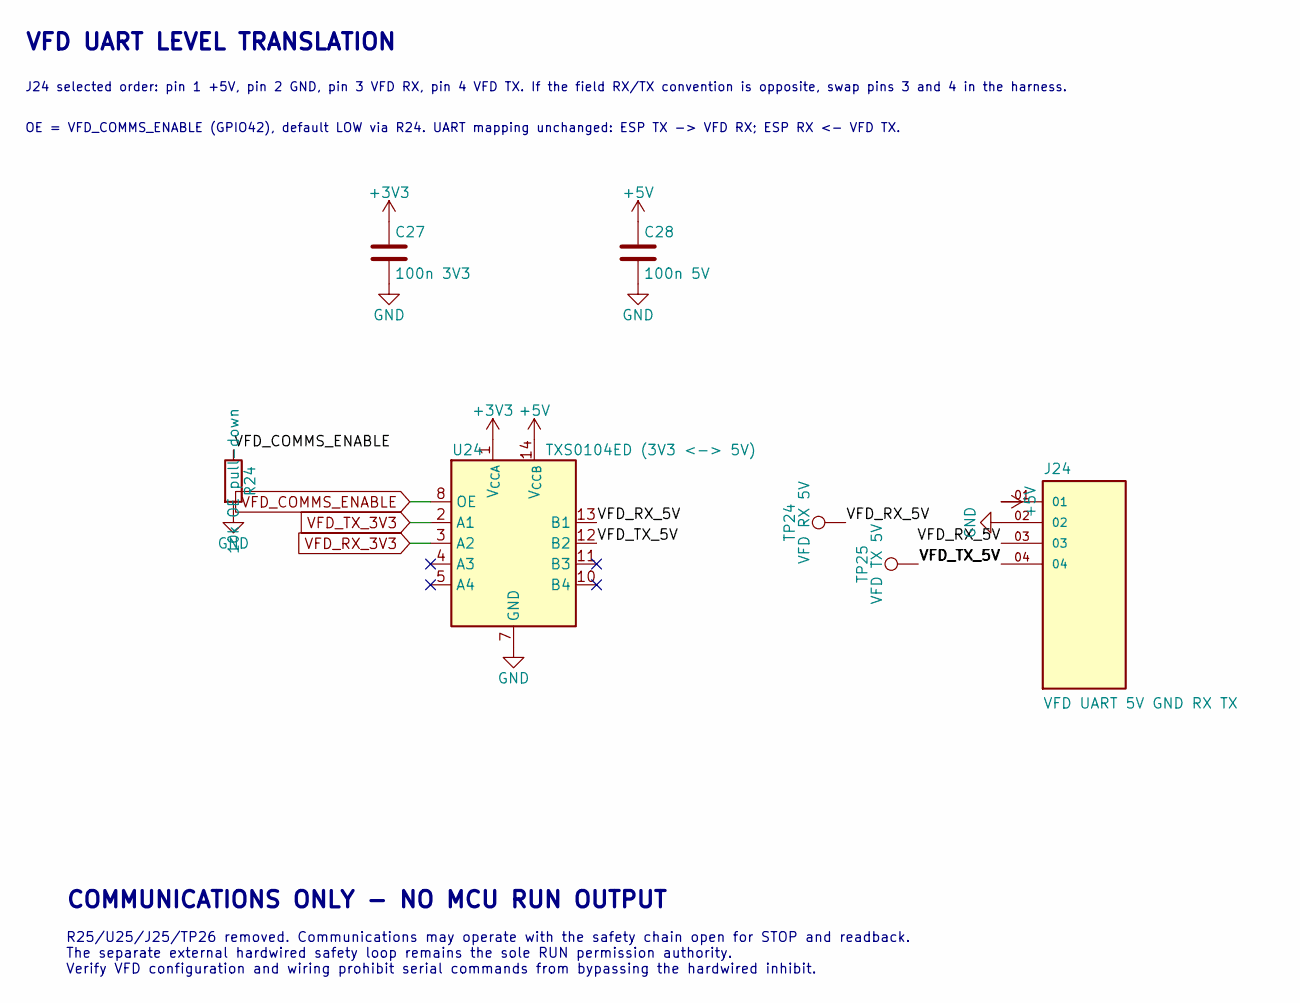
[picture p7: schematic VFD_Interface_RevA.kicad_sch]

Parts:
C27: 100n 3V3; C_0603_1608Metric
C28: 100n 5V; C_0603_1608Metric
J24: VFD UART 5V GND RX TX; SAMTEC_TSW-104-07-G-S_ZeroPadded
R24: 10k OE pull-down; R_0603_1608Metric
TP24: VFD RX 5V; TestPoint_Pad_D1.0mm
TP25: VFD TX 5V; TestPoint_Pad_D1.0mm
U24: TXS0104ED (3V3 <-> 5V); SOIC-14_3.9x8.7mm_P1.27mm; MPN TXS0104EDR

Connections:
+3V3: C27.1, U24.1 (V_{CCA}); also elsewhere on the board
+5V: C28.1, J24.01, U24.14 (V_{CCB}); also elsewhere on the board
/VFD_Interface/VFD_RX_5V: J24.03, TP24.1 (1_1), U24.13 (B1)
/VFD_Interface/VFD_TX_5V: J24.04, TP25.1 (1_1), U24.12 (B2)
GND: C27.2, C28.2, J24.02, R24.2, U24.7 (GND); also elsewhere on the board
VFD_COMMS_ENABLE: R24.1, U24.8 (OE); also elsewhere on the board
VFD_RX_3V3: U24.3 (A2); also elsewhere on the board
VFD_TX_3V3: U24.2 (A1); also elsewhere on the board

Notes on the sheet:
J24 selected order: pin 1 +5V, pin 2 GND, pin 3 VFD RX, pin 4 VFD TX. If the field RX/TX convention is opposite, swap pins 3 and 4 in the harness.
COMMUNICATIONS ONLY - NO MCU RUN OUTPUT
OE = VFD_COMMS_ENABLE (GPIO42), default LOW via R24. UART mapping unchanged: ESP TX -> VFD RX; ESP RX <- VFD TX.
VFD UART LEVEL TRANSLATION
R25/U25/J25/TP26 removed. Communications may operate with the safety chain open for STOP and readback. The separate external hardwired safety loop remains the sole RUN permission authority. Verify VFD configuration and wiring prohibit serial commands from bypassing the hardwired inhibit.

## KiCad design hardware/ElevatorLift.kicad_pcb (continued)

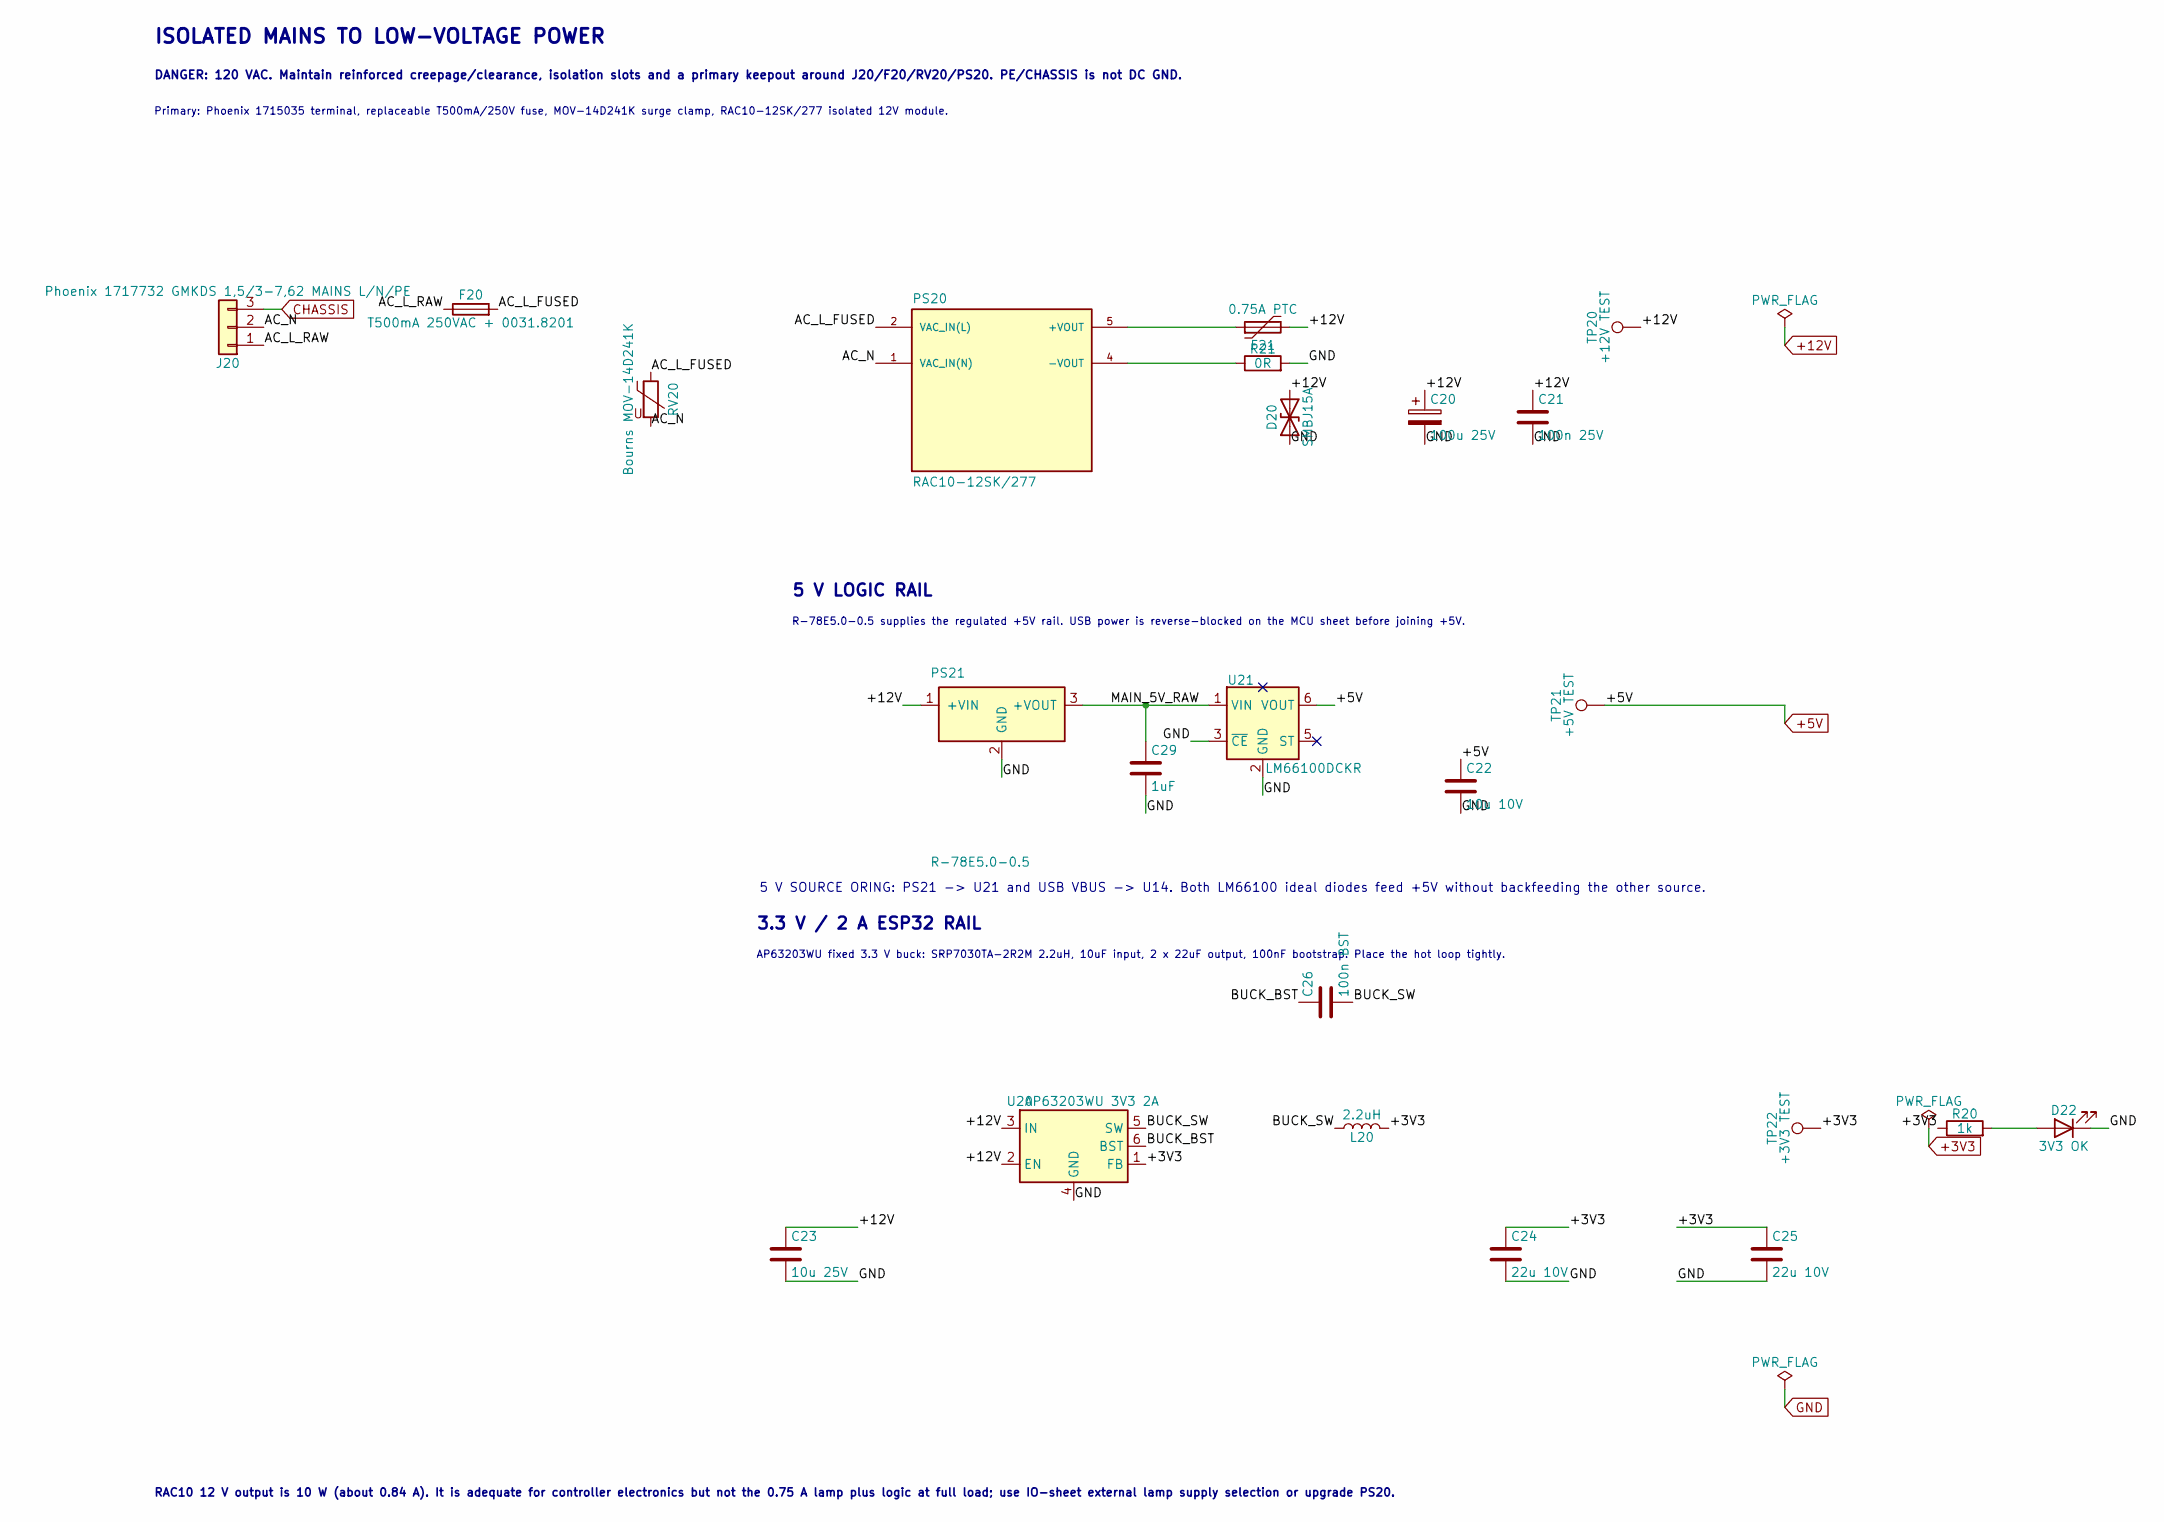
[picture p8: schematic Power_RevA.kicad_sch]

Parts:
C20: 100u 25V; CP_Radial_D8.0mm_P3.50mm
C21: 100n 25V; C_0603_1608Metric
C22: 10u 10V; C_0805_2012Metric
C23: 10u 25V; C_1206_3216Metric
C24, C25: 22u 10V; C_1206_3216Metric
C26: 100n BST; C_0603_1608Metric
C29: 1uF; C_0603_1608Metric
D20: SMBJ15A; D_SMB
D22: 3V3 OK; LED_0603_1608Metric
F20: T500mA 250VAC + 0031.8201; Fuseholder_Cylinder-5x20mm_Schurter_0031_8201_Horizontal_Op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
F21: 0.75A PTC; Fuse_1812_4532Metric; MPN MF-MSMF075/24X
J20: Phoenix 1717732 GMKDS 1,5/3-7,62 MAINS L/N/PE; Phoenix_GMKDS-1.5-3-7.62_1717732_Provisional
L20: 2.2uH; L_Bourns_SRP7028A_7.3x6.6mm; MPN SRP7028A-2R2M
PS20: RAC10-12SK/277; CONV_RAC10-12SK_277
PS21: R-78E5.0-0.5; CONV_R-78E5.0-0.5
R20: 1k; R_0603_1608Metric
R21: 0R; R_0603_1608Metric
RV20: Bourns MOV-14D241K; RV_Disc_D15.5mm_W5.2mm_P7.5mm
TP20: +12V TEST; TestPoint_Pad_D1.0mm
TP21: +5V TEST; TestPoint_Pad_D1.0mm
TP22: +3V3 TEST; TestPoint_Pad_D1.0mm
U20: AP63203WU 3V3 2A; TSOT-23-6; MPN AP63203WU-7
U21: LM66100DCKR; SOT-363_SC-70-6; MPN LM66100DCKR

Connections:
+3V3: C24.1, C25.1, L20.2, R20.1, TP22.1 (1_1), U20.1 (FB); also elsewhere on the board
+5V: C22.1, TP21.1 (1_1), U21.6 (VOUT); also elsewhere on the board
+12V: C20.1, C21.1, C23.1, D20.2 (A2), F21.2, PS21.1 (+VIN), TP20.1 (1_1), U20.2 (EN), U20.3 (IN); also elsewhere on the board
/Power/AC_L_FUSED: F20.2, PS20.2 (VAC_IN(L)), RV20.1
/Power/AC_L_RAW: F20.1, J20.1
/Power/AC_N: J20.2, PS20.1 (VAC_IN(N)), RV20.2
/Power/BUCK_BST: C26.1, U20.6 (BST)
/Power/BUCK_SW: C26.2, L20.1, U20.5 (SW)
/Power/MAIN_5V_RAW: C29.1, PS21.3 (+VOUT), U21.1 (VIN)
CHASSIS: J20.3; also elsewhere on the board
GND: C20.2, C21.2, C22.2, C23.2, C24.2, C25.2, C29.2, D20.1 (A1), D22.1 (K), PS21.2 (GND), R21.2, U20.4 (GND), U21.2 (GND), U21.3 (~CE); also elsewhere on the board
unnamed: D22.2 (A), R20.2
unnamed: F21.1, PS20.5 (+VOUT)
unnamed: PS20.4 (-VOUT), R21.1

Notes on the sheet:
ISOLATED MAINS TO LOW-VOLTAGE POWER
5 V LOGIC RAIL
3.3 V / 2 A ESP32 RAIL
Primary: Phoenix 1715035 terminal, replaceable T500mA/250V fuse, MOV-14D241K surge clamp, RAC10-12SK/277 isolated 12V module.
AP63203WU fixed 3.3 V buck: SRP7030TA-2R2M 2.2uH, 10uF input, 2 x 22uF output, 100nF bootstrap. Place the hot loop tightly.
DANGER: 120 VAC. Maintain reinforced creepage/clearance, isolation slots and a primary keepout around J20/F20/RV20/PS20. PE/CHASSIS is not DC GND.
5 V SOURCE ORING: PS21 -> U21 and USB VBUS -> U14. Both LM66100 ideal diodes feed +5V without backfeeding the other source.
R-78E5.0-0.5 supplies the regulated +5V rail. USB power is reverse-blocked on the MCU sheet before joining +5V.
RAC10 12 V output is 10 W (about 0.84 A). It is adequate for controller electronics but not the 0.75 A lamp plus logic at full load; use IO-sheet external lamp supply selection or upgrade PS20.

Board: 4 copper layers, 126 parts (51 on the bottom side), 92 nets, no tracks yet.

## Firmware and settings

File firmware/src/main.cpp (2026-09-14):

#include <Arduino.h>
#include <ArduinoJson.h>
#include <ESPmDNS.h>
#include <LittleFS.h>
#include <SPI.h>
#include <WiFi.h>
#include <Wire.h>
#include <esp_log.h>
#include <esp_rom_sys.h>
#include <mbedtls/sha256.h>

#include "NetworkConfig.h"
#include "PinMap.h"
#include "VfdParameters.h"
#include "core/Configuration.h"
#include "core/Devices.h"
#include "core/DiagnosticVfd.h"
#include "core/FieldInputs.h"
#include "core/HttpRequest.h"
#include "core/ManualStop.h"
#include "core/SafetyLedger.h"
#include "core/Supervisor.h"
#if __has_include("Secrets.h")
#include "Secrets.h"
#else
#include "Secrets.example.h"
#endif
#ifndef LIFT_API_TOKEN
#define LIFT_API_TOKEN ""
#endif
namespace {
class BoardSpi final : public lift::SpiBus {
 public:
  bool transfer(int cs, const uint8_t* tx, uint8_t* rx, size_t n) override {
    if (n > 68 || (cs != Pins::CounterCs && cs != Pins::MramCs))
      return false;
    SPI.beginTransaction(SPISettings(1000000, MSBFIRST, SPI_MODE0));
    digitalWrite(cs, LOW);
    for (size_t i = 0; i < n; ++i)
      rx[i] = SPI.transfer(tx[i]);
    digitalWrite(cs, HIGH);
    SPI.endTransaction();
    return true;
  }
} spi;
class BoardI2c final : public lift::I2cBus {
 public:
  bool read(uint8_t device, uint8_t reg, uint8_t* out, size_t n) override {
    Wire.beginTransmission(device);
    Wire.write(reg);
    if (Wire.endTransmission(false) != 0)
      return false;
    if (Wire.requestFrom(device, uint8_t(n)) != n)
      return false;
    for (size_t i = 0; i < n; ++i)
      out[i] = Wire.read();
    return true;
  }
} i2c;
lift::Counter counter(spi, Pins::CounterCs);
lift::Mram mram(spi, Pins::MramCs);
lift::Rtc rtc(i2c);
lift::Journal snapshots(mram, 0, 2), configurationRecords(mram, 2048, 2),
    safetyRecords(mram, 4096, 2), events(mram, 8192, 768);
lift::SafetyLedger safetyLedger(safetyRecords);
lift::ConfigurationStore configurationStore(configurationRecords);
lift::Configuration configuration;
lift::Supervisor supervisor;
lift::FieldInputs fieldInputs;
lift::DiagnosticVfd diagnosticVfd;
lift::ManualStop manualStop;
HardwareSerial VfdSerial(1);
bool vfdUartReady = false;
constexpr bool FieldContinuityQualified = false;
int discardUartLog(const char*, va_list) { return 0; }
void serviceVfd(uint32_t now) {
  if (!vfdUartReady)
    return;
  for (unsigned n = 0; n < 64 && VfdSerial.available(); ++n)
    diagnosticVfd.receive(char(VfdSerial.read()), now);
  // All frames fit in the hardware TX queue; do not block the supervisor loop.
  if (VfdSerial.availableForWrite() >= 32) {
    const auto frame = diagnosticVfd.transmit(now);
    if (!frame.empty())
      VfdSerial.write(reinterpret_cast<const uint8_t*>(frame.data()), frame.size());
  }
}
NetworkConfig networkStore;
NetworkSettings network;
WiFiServer http(80);
WiFiClient client;
lift::HttpRequest request;
File asset;
String response;
size_t responseOffset = 0;
uint32_t connectedAt = 0, lastSample = 0, lastNetwork = 0, lastRtc = 0, lastPersist = 0,
         unixTime = 0, statusSequence = 0;
bool responding = false, ap = false, counterReady = false, storageReady = false, rtcValid = false,
     fsReady = false;
int64_t position = 0;
const char* previousFault = "";
const char* previousWatchdogState = "unknown";
bool vfdFailureLogged = false;
char bootId[17] = {};
uint32_t lastWriteRequestMs = 0;
String counts(int64_t n) {
  char b[24];
  snprintf(b, sizeof b, "%lld", static_cast<long long>(n));
  return b;
}
bool tokenConfigured() { return strlen(LIFT_API_TOKEN) >= 16; }
bool verifyWebBundle() {
  File manifest = LittleFS.open("/bundle-manifest.json", "r");
  if (!manifest || manifest.size() > 8192)
    return false;
  JsonDocument d;
  if (deserializeJson(d, manifest) || d["apiVersion"] != 1 ||
      d["contractVersion"] != Pins::ContractVersion)
    return false;
  JsonArray files = d["files"].as<JsonArray>();
  if (files.size() < 2 || files.size() > 32)
    return false;
  size_t total = 0;
  bool index = false;
  for (JsonObject entry : files) {
    const char* name = entry["path"] | "";
    const char* expected = entry["sha256"] | "";
    String path = name;
    if (path.length() > 128 || path.indexOf("..") >= 0 || path.indexOf('\\') >= 0 ||
        path.startsWith("/") || strlen(expected) != 64)
      return false;
    if (path != "index.html" && path != "index.html.gz" && !path.startsWith("assets/"))
      return false;
    File file = LittleFS.open("/" + path, "r");
    size_t size = entry["bytes"] | 0;
    if (!file || file.size() != size || size > 2097152 || total > 2097152 - size)
      return false;
    total += size;
    mbedtls_sha256_context hash;
    mbedtls_sha256_init(&hash);
    mbedtls_sha256_starts_ret(&hash, 0);
    uint8_t buffer[256], digest[32];
    while (file.available()) {
      size_t n = file.read(buffer, sizeof buffer);
      if (!n) {
        mbedtls_sha256_free(&hash);
        return false;
      }
      mbedtls_sha256_update_ret(&hash, buffer, n);
    }
    mbedtls_sha256_finish_ret(&hash, digest);
    mbedtls_sha256_free(&hash);
    char actual[65];
    for (unsigned i = 0; i < 32; ++i)
      snprintf(actual + 2 * i, 3, "%02x", digest[i]);
    if (strcmp(actual, expected))
      return false;
    if (path == "index.html")
      index = true;
  }
  return index;
}
void event(const char* code, const char* source, const char* result) {
  if (!storageReady)
    return;
  JsonDocument d;
  d["code"] = code;
  d["source"] = source;
  d["result"] = result;
  d["uptimeMs"] = millis();
  d["position"] = counts(position);
  if (rtcValid)
    d["unixTime"] = unixTime;
  else
    d["unixTime"] = nullptr;
  char bytes[lift::Journal::PayloadMax];
  size_t n = serializeJson(d, bytes, sizeof bytes);
  if (n >= sizeof bytes || !events.append(reinterpret_cast<uint8_t*>(bytes), n))
    storageReady = false;
}
JsonDocument status() {
  JsonDocument d;
  d["apiVersion"] = 1;
  d["contractVersion"] = Pins::ContractVersion;
  d["bootId"] = bootId;
  d["sequence"] = ++statusSequence;
  d["uptimeMs"] = millis();
  d["sampleAgeMs"] = millis() - lastSample;
  d["state"] = lift::stateName(supervisor.state);
  d["deploymentReady"] = false;
  d["position"] = counts(position);
  d["positionValid"] = false;
  d["currentFloor"] = nullptr;
  d["targetFloor"] = nullptr;
  d["motionAllowed"] = false;
  d["canMoveUp"] = false;
  d["canMoveDown"] = false;
  d["stoppedConfirmed"] = false;  // Physical qualification is still absent.
  d["safetyOk"] = supervisor.inputs.safety;
  d["home"] = supervisor.inputs.home;
  const uint32_t now = millis();
  if (fieldInputs.upper.fresh(now))
    d["upperLimit"] = fieldInputs.upper.active;
  else
    d["upperLimit"] = nullptr;
  if (fieldInputs.lower.fresh(now))
    d["lowerLimit"] = fieldInputs.lower.active;
  else
    d["lowerLimit"] = nullptr;
  if (fieldInputs.key.fresh(now))
    d["serviceKey"] = fieldInputs.key.active;
  else
    d["serviceKey"] = nullptr;
  d["inputsQualified"] = fieldInputs.qualified(now, FieldContinuityQualified);
  d["manualControl"]["active"] = manualStop.key;
  d["manualControl"]["hold"] = manualStop.hold;
  d["manualControl"]["up"] = manualStop.up;
  d["manualControl"]["down"] = manualStop.down;
  d["manualControl"]["safetyHealthy"] = manualStop.safety;
  d["manualControl"]["inputsKnown"] = manualStop.known;
  d["manualControl"]["requestedDirection"] = manualStop.requestedDirection;
  d["manualControl"]["motionEnabled"] = false;
  d["fault"] = supervisor.fault;
  auto reasons = d["blockedReasons"].to<JsonArray>();
  for (const char* r :
       {"software-motion-inhibit", "field-inputs-unqualified", "physical-qualification-required"})
    reasons.add(r);
  auto caps = d["capabilities"].to<JsonObject>();
  for (const char* cap :
       {"motion", "homing", "calibration", "floorWrite", "settingsWrite", "vfdRead", "vfdWrite",
        "rfLearn", "rfErase", "backup", "restore", "reboot", "auxiliary"})
    caps[cap] = false;
  caps["status"] = true;
  caps["vfdRead"] = vfdUartReady;
  caps["network"] = tokenConfigured();
  caps["light"] = tokenConfigured();
  caps["logs"] = storageReady;
  auto floors = d["floors"].to<JsonArray>();
  for (int f = 1; f <= 3; ++f) {
    auto floor = floors.add<JsonObject>();
    floor["floor"] = f;
    floor["name"] = *configuration.names[f - 1].data() ? String(configuration.names[f - 1].data())
                                                       : String("Landing ") + f;
    if (configuration.motion.floorsValid)
      floor["position"] = counts(configuration.motion.floors[f - 1]);
    else
      floor["position"] = nullptr;
  }
  d["light"]["on"] = supervisor.light;
  d["light"]["feedbackVerified"] = false;
  d["telemetry"] = nullptr;
  if (diagnosticVfd.healthy(now)) {
    const auto& t = diagnosticVfd.protocol().telemetry;
    d["telemetry"]["ageMs"] = now - t.sampledMs;
    d["telemetry"]["frequency"] = t.frequency;
    d["telemetry"]["current"] = t.current;
    d["telemetry"]["busVolts"] = t.busVolts;
    d["telemetry"]["temperature"] = t.temperature;
  }
  d["vfd"]["commsEnabled"] = vfdUartReady;
  d["vfd"]["healthy"] = diagnosticVfd.healthy(now);
  d["vfd"]["stopTransmitted"] = diagnosticVfd.stopTransmitted;
  d["vfd"]["stopAcknowledged"] = diagnosticVfd.acknowledged();
  d["vfd"]["monitorStopped"] = diagnosticVfd.monitorStopped(now);
  d["vfd"]["communicationFault"] = diagnosticVfd.failed;
  d["vfd"]["stopRefreshMs"] = lift::VfdTiming::StopRefreshMs;
  d["vfd"]["replyTimeoutMs"] = lift::VfdTiming::ReplyTimeoutMs;
  d["vfd"]["watchdog"]["state"] = diagnosticVfd.watchdogState(now);
  const auto& p = diagnosticVfd.protocol();
  if (p.parameters[12] >= 0) {
    d["vfd"]["watchdog"]["timeoutMs"] = p.parameters[12] * 100;
    d["vfd"]["watchdog"]["ageMs"] = now - p.parameterSampleMs[12];
  } else {
    d["vfd"]["watchdog"]["timeoutMs"] = nullptr;
    d["vfd"]["watchdog"]["ageMs"] = nullptr;
  }
  d["calibration"]["valid"] = false;
  d["calibration"]["distance"] = nullptr;
  d["devices"]["counter"] = counterReady ? "sampled-unverified" : "unavailable";
  d["devices"]["mram"] = storageReady ? "readback-unverified" : "unavailable";
  d["devices"]["rtc"] = rtcValid ? "sampled-unverified" : "time-invalid";
  d["network"]["mode"] = WiFi.status() == WL_CONNECTED ? "station" : "fallback_ap";
  d["network"]["stationIp"] = WiFi.status() == WL_CONNECTED ? WiFi.localIP().toString() : "";
  d["network"]["apIp"] = ap ? WiFi.softAPIP().toString() : "";
  d["network"]["hostname"] = "lift.local";
  d["authConfigured"] = tokenConfigured();
  return d;
}
void reply(int code, const JsonDocument& d) {
  asset.close();
  String json;
  serializeJson(d, json);
  response =
      "HTTP/1.1 " + String(code) +
      " Response\r\nContent-Type: application/json\r\nCache-Control: no-store\r\nConnection: "
      "close\r\nX-Content-Type-Options: nosniff\r\nContent-Length: " +
      String(json.length()) + "\r\n\r\n" + json;
  responseOffset = 0;
  responding = true;
}
void error(int code, const char* reason) {
  JsonDocument d;
  d["error"] = reason;
  d["apiVersion"] = 1;
  reply(code, d);
}
bool authorized() {
  auto it = request.headers.find("x-lift-api-token");
  return tokenConfigured() && it != request.headers.end() && it->second == LIFT_API_TOKEN;
}
void dispatch() {
  std::map<std::string, std::string> args;
  if (!lift::HttpRequest::form(request.query, args) ||
      !lift::HttpRequest::form(request.body, args)) {
    error(400, "invalid_arguments");
    return;
  }
  const auto& path = request.path;
  bool post = request.method == "POST";
  if (post && !authorized()) {
    error(401, "authentication_required");
    return;
  }
  if (post && path != "/api/stop") {
    uint32_t now = millis();
    if (now - lastWriteRequestMs < 250) {
      error(429, "write_rate_limited");
      return;
    }
    lastWriteRequestMs = now;
  }
  if (path == "/api/status" && !post) {
    reply(200, status());
    return;
  }
  if (path == "/api/capabilities" && !post) {
    auto s = status();
    JsonDocument d;
    d["apiVersion"] = 1;
    d["capabilities"] = s["capabilities"];
    reply(200, d);
    return;
  }
  if (path == "/api/stop" && post) {
    if (!args.empty()) {
      error(400, "unexpected_argument");
      return;
    }
    supervisor.command({true, 0, lift::Source::Web}, millis());
    if (!vfdUartReady) {
      error(503, "stop_delivery_unavailable");
      return;
    }
    diagnosticVfd.stop(millis());
    event("stop", "web", "queued-not-confirmed-stopped");
    reply(202, status());
    return;
  }
  if (path == "/api/move" && post) {
    if (manualStop.key || !manualStop.known) {
      error(409, "manual_control_priority");
      return;
    }
    uint32_t floor = 0;
    if (args.size() != 1 || !args.count("floor") ||
        !lift::parseUnsigned(args["floor"].c_str(), 3, floor) || floor < 1) {
      error(400, "invalid_floor");
      return;
    }
    const char* reason =
        supervisor.command({false, 1u << (floor - 1), lift::Source::Web}, millis());
    event("move", "web", reason ? reason : "accepted");
    if (reason)
      error(409, reason);
    else
      reply(202, status());
    return;
  }
  if (path == "/api/light" && post) {
    if (args.size() != 1 || !args.count("on") || (args["on"] != "true" && args["on"] != "false")) {
      error(400, "invalid_light_state");
      return;
    }
    supervisor.setLight(args["on"] == "true");
    digitalWrite(Pins::LightControl, supervisor.light ? HIGH : LOW);
    event("light", "web", supervisor.light ? "on-commanded" : "off-commanded");
    reply(200, status());
    return;
  }
  if (path == "/api/network" && !post) {
    auto s = status();
    JsonDocument d;
    d["apiVersion"] = 1;
    d["network"] = s["network"];
    d["ssid"] = network.staSsid;
    reply(200, d);
    return;
  }
  if (path == "/api/network" && post) {
    if (args.size() != 2 || !args.count("ssid") || !args.count("password") ||
        args["ssid"].size() > 32 || args["password"].size() > 63 ||
        (!args["password"].empty() && args["password"].size() < 8)) {
      error(400, "invalid_network_settings");
      return;
    }
    if (supervisor.runRequested() || supervisor.state == lift::State::Stopping) {
      error(409, "stop_required");
      return;
    }
    NetworkSettings updated = network;
    snprintf(updated.staSsid, sizeof updated.staSsid, "%s", args["ssid"].c_str());
    snprintf(updated.staPassword, sizeof updated.staPassword, "%s", args["password"].c_str());
    if (!networkStore.save(updated)) {
      error(500, "network_save_failed");
      return;
    }
    network = updated;
    event("network_saved", "web", "restart-required");
    JsonDocument d;
    d["apiVersion"] = 1;
    d["saved"] = true;
    d["restartRequired"] = true;
    reply(200, d);
    return;
  }
  if (path == "/api/logs/recent" && !post) {
    if (!storageReady) {
      error(503, "durable_log_unavailable");
      return;
    }
    if (!args.empty()) {
      error(400, "unexpected_argument");
      return;
    }
    JsonDocument d;
    d["apiVersion"] = 1;
    d["durable"] = true;
    auto rows = d["events"].to<JsonArray>();
    uint32_t seq = events.sequence();
    for (unsigned count = 0; count < 16 && seq; ++count, --seq) {
      uint8_t p[lift::Journal::PayloadMax];
      size_t n = sizeof p;
      if (!events.readSequence(seq, p, n))
        continue;
      JsonDocument row;
      if (deserializeJson(row, p, n))
        continue;
      row["sequence"] = seq;
      rows.add(row.as<JsonObject>());
    }
    reply(200, d);
    return;
  }
  if (path == "/api/vfd/parameters" && !post) {
    JsonDocument d;
    d["apiVersion"] = 1;
    d["available"] = diagnosticVfd.healthy(millis());
    d["reason"] = d["available"].as<bool>() ? "diagnostic-readback-only" : "vfd_unavailable";
    auto readings = d["readings"].to<JsonArray>();
    for (unsigned n = 0; n < 17; ++n) {
      auto r = readings.add<JsonObject>();
      r["number"] = n;
      const auto& p = diagnosticVfd.protocol();
      r["supported"] = n != 13;
      if (p.parameters[n] >= 0) {
        r["rawValue"] = p.parameters[n];
        r["ageMs"] = millis() - p.parameterSampleMs[n];
      } else {
        r["rawValue"] = nullptr;
        r["ageMs"] = nullptr;
      }
    }
    JsonDocument definitions;
    deserializeJson(definitions, VfdParameters::allDefinitionsJson());
    d["definitions"] = definitions;
    reply(200, d);
    return;
  }
  if (path.compare(0, 5, "/api/") == 0) {
    error(501, "unsupported_capability");
    return;
  }
  if (post || !args.empty() || path.find("..") != std::string::npos ||
      path.find('%') != std::string::npos) {
    error(404, "not_found");
    return;
  }
  String file = path == "/" ? "/index.html" : path.c_str();
  if (!fsReady || (!file.startsWith("/assets/") && file != "/index.html")) {
    error(503, "web_bundle_unavailable");
    return;
  }
  bool gzip = request.headers["accept-encoding"].find("gzip") != std::string::npos &&
              LittleFS.exists(file + ".gz");
  asset = LittleFS.open(gzip ? file + ".gz" : file, "r");
  if (!asset) {
    error(404, "asset_not_found");
    return;
  }
  const char* mime = file.endsWith(".js")    ? "text/javascript"
                     : file.endsWith(".css") ? "text/css"
                                             : "text/html";
  response = "HTTP/1.1 200 OK\r\nConnection: close\r\nContent-Type: " + String(mime) +
             "\r\nX-Content-Type-Options: nosniff\r\nContent-Security-Policy: default-src 'self'; "
             "script-src 'self'; style-src 'self' 'unsafe-inline'; connect-src 'self'; "
             "frame-ancestors 'none'\r\nVary: Accept-Encoding\r\nCache-Control: " +
             String(file == "/index.html" ? "no-cache" : "public, max-age=31536000, immutable") +
             "\r\nContent-Length: " + String(asset.size()) + "\r\n" +
             (gzip ? "Content-Encoding: gzip\r\n" : "") + "\r\n";
  responseOffset = 0;
  responding = true;
}
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
void loop() {
  uint32_t now = millis();
  // Sample release paths before any UART scheduling, HTTP, SPI or persistent logging.
  const char* manualEvent = manualStop.update(
      digitalRead(Pins::ServiceKey), digitalRead(Pins::HoldToRun), digitalRead(Pins::ServiceUp),
      digitalRead(Pins::ServiceDown), digitalRead(Pins::SafetyLoop), now);
  if (manualEvent) {
    supervisor.stop(now);
    diagnosticVfd.stop(now);
  }
  serviceVfd(now);
  if (diagnosticVfd.failed && !vfdFailureLogged) {
    event("vfd_communication_timeout", "vfd", "fault-latched-stop-refresh-only");
    vfdFailureLogged = true;
  }
  const char* watchdogState = diagnosticVfd.watchdogState(now);
  if (strcmp(watchdogState, previousWatchdogState)) {
    event("vfd_watchdog_state", "vfd", watchdogState);
    previousWatchdogState = watchdogState;
  }
  if (manualEvent)
    event(manualEvent, "manual", "stop-queued-not-confirmed-stopped");
  if (now - lastSample >= 10) {
    counterReady = counterReady && counter.sample(position);
    lift::Inputs i;
    i.sampleMs = now;
    i.position = position;
    i.encoderHealthy = counterReady;
    i.storageHealthy = storageReady;
    i.safety = digitalRead(Pins::SafetyLoop) == LOW;
    i.home = digitalRead(Pins::HomeSwitch) == LOW;
    i.hold = digitalRead(Pins::HoldToRun) == LOW;
    i.up = digitalRead(Pins::ServiceUp) == LOW;
    i.down = digitalRead(Pins::ServiceDown) == LOW;
    fieldInputs.upper.sample(digitalRead(Pins::UpperLimit), now);
    fieldInputs.lower.sample(digitalRead(Pins::LowerLimit), now);
    fieldInputs.key.sample(digitalRead(Pins::ServiceKey), now);
    i.upper = fieldInputs.upper.active;
    i.lower = fieldInputs.lower.active;
    i.key = fieldInputs.key.active;
    i.limitsKnown = i.keyKnown = fieldInputs.qualified(now, FieldContinuityQualified);
    i.hardwareReady = Pins::DeploymentReady;
    i.communicationHealthy = diagnosticVfd.healthy(now);
    i.stopped = diagnosticVfd.monitorStopped(now);
    i.frequency = diagnosticVfd.protocol().telemetry.frequency;
    supervisor.tick(i, now);
    lastSample = now;
    digitalWrite(Pins::RfLearn, LOW);
    if (previousFault != supervisor.fault) {
      if (storageReady && !safetyLedger.latchFault())
        storageReady = false;
      event("fault", "controller", supervisor.fault);
      previousFault = supervisor.fault;
    }
  }
  if (now - lastRtc >= 1000) {
    rtcValid = rtc.readUnix(unixTime);
    lastRtc = now;
  }
  if (storageReady && now - lastPersist >= 1000) {
    uint8_t p[24] = {};
    lift::put32(p, 1);
    lift::put32(p + 4, now);
    lift::put32(p + 8, uint64_t(position));
    lift::put32(p + 12, uint64_t(position) >> 32);
    p[16] = 0;
    p[17] = uint8_t(supervisor.state);
    storageReady = snapshots.append(p, sizeof p);
    lastPersist = now;
  }
  serviceHttp(now);
  if (now - lastNetwork >= 5000) {
    lastNetwork = now;
    if (WiFi.status() != WL_CONNECTED)
      startAp();
    else if (ap) {
      WiFi.softAPdisconnect(true);
      ap = false;
      WiFi.mode(WIFI_STA);
      MDNS.begin("lift");
      MDNS.addService("http", "tcp", 80);
    }
  }
  delay(1);
}

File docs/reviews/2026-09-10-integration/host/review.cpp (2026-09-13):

// Executes unmodified application logic, not a reimplementation of its state machine.
#include "../../../../firmware/src/main.cpp"
#include <iostream>
int failures=0,checks=0;
void check(bool result,const char* name){++checks;std::cout<<(result?"CONFIRMED ":"NOT REPRODUCED ")<<name<<"\n";if(!result)++failures;}
void reset(){
  fakeMs=1000;fakePins.clear();
  fakePins[Pins::SafetyLoop]=LOW;
  for(int p:{Pins::ButtonTop,Pins::ButtonRight,Pins::ButtonBottom,Pins::ButtonLeft,Pins::ButtonCenter})fakePins[p]=LOW;
  motionState=MotionState::Idle;activeCommand={};pulsePositionCounts=0;lastFault="";lastVfdCommand="";vfdRxBuffer="";
  VfdSerial.sent.clear();VfdSerial.incoming="";lastVfdCommandMs=0;lastStopCommandMs=0;
  restartRequested=false;ESP.restarted=false;fallbackApEnabled=false;mdnsStarted=false;lastPersistMs=0;lastWifiCheckMs=0;lastButtonTop=lastButtonRight=lastButtonBottom=lastButtonLeft=lastButtonCenter=false;
  Preferences::data.clear();Preferences::failWrites=false;store.begin();liftSettingsStore.begin();networkConfig.begin();
  storedState={};networkSettings={};liftSettings={};eventLog.begin();
  server.headers.clear();server.headers[ApiAuth::TokenHeader]="review-test-token";
}
int main(){
  setupWebServer();reset();
  check(VfdProtocol::stop()=="(3)84" && VfdProtocol::monitor()=="(0)81","protocol documented stop/monitor vectors");
  check(VfdProtocol::run(VfdDirection::Forward,450)=="(10450)4;","protocol 45Hz forward vector");
  check(VfdProtocol::isStopAck("noise(3)84unframed"),"DEFECT acknowledgement accepts unframed substring");
  reset();setup();check(motionState==MotionState::Idle && readPositionCounts()==0,"DEFECT fresh empty NVS boots idle at invented zero");
  check(VfdSerial.sent.size()==4 && VfdSerial.sent[0]!=VfdProtocol::stop(),"DEFECT boot writes four drive parameters without initial STOP or ACK");
  reset();requestMoveToFloor(2);fakeMs=3600000;serviceMotion();check(motionState==MotionState::Moving && !VfdSerial.sent.empty(),"DEFECT no encoder pulses or VFD replies for one hour still requests run");
  reset();requestMoveToFloor(2);setPositionCounts(25000);serviceMotion();check(motionState==MotionState::Moving,"DEFECT overshot stop window continues forward");
  reset();vfdRxBuffer="(3)84";beginStopping();serviceVfdRx();check(motionState==MotionState::Idle,"DEFECT stale stop ACK marks new stop idle");
  reset();enterFault("test_fault");server.call("/api/stop",HTTP_POST);VfdSerial.incoming="(3)84";serviceVfdRx();check(motionState==MotionState::Idle && requestMoveToFloor(2),"DEFECT STOP then ACK bypasses fault latch without explicit reset");
  reset();fakePins[Pins::SafetyLoop]=HIGH;check(!requestMoveToFloor(2)&&motionState==MotionState::Fault,"safety-open request rejected and STOP emitted");
  reset();requestMoveToFloor(2);fakePins[Pins::UpperLimit]=LOW;serviceMotion();check(motionState==MotionState::Fault,"forward active upper limit faults under provisional GPIO mapping");
  reset();beginStopping();fakeMs+=2001;serviceMotion();check(motionState==MotionState::Fault,"missing stop ACK timeout faults");
  auto n=VfdSerial.sent.size();fakeMs+=10000;serviceMotion();check(VfdSerial.sent.size()==n,"DEFECT fault state stops STOP retrying");
  reset();setPositionCounts(40000);fakePins[Pins::HomeSwitch]=LOW;serviceMotion();check(readPositionCounts()==0,"DEFECT top HOME resets coordinate to floor-one zero");
  reset();server.call("/api/settings",HTTP_POST,{{"stopOffsetCounts","17"}});requestMoveToFloor(2);check(server.code==200&&liftSettings.stopOffsetCounts==17&&activeCommand.stopOffsetCounts==3500,"DEFECT accepted stored stopping offset not used by motion");
  server.call("/api/settings",HTTP_POST,{{"normalRunTenthsHz","700"}});serviceMotion();check(server.code==200 && lastVfdCommand==VfdProtocol::run(VfdDirection::Forward,700),"DEFECT settings update changes commanded speed during movement");
  reset();server.call("/api/move",HTTP_POST,{{"floor","258"}});check(server.code==202&&activeCommand.floor==2,"DEFECT invalid floor258 wraps to floor2");
  reset();server.call("/api/move",HTTP_POST,{{"floor","2junk"}});check(server.code==202,"DEFECT partially numeric command accepted");
  reset();server.call("/api/vfd/parameter",HTTP_POST,{{"number","266"},{"value","1000"}});check(server.code==202,"DEFECT parameter266 wraps to FMAX10");
  reset();requestMoveToFloor(2);server.call("/api/vfd/parameter",HTTP_POST,{{"number","3"},{"value","10"}});check(server.code==409,"parameter write blocked while moving");
  server.headers.clear();server.call("/api/vfd/parameter",HTTP_GET,{{"number","3"}});check(server.code==202&&!VfdSerial.sent.empty(),"DEFECT unauthenticated parameter read sends UART during motion without arbiter");
  reset();server.headers.clear();server.call("/api/move",HTTP_POST,{{"floor","2"}});check(server.code==401,"configured token rejects unauthorized writes");
  reset();requestMoveToFloor(2);server.call("/api/reboot",HTTP_POST);check(server.code==202&&restartRequested&&motionState==MotionState::Moving,"DEFECT reboot accepted while moving without STOP");
  fakeMs=restartAtMs;loop();check(ESP.restarted&&motionState==MotionState::Moving,"DEFECT main loop restarts with active run state");
  reset();server.call("/api/light/toggle",HTTP_POST);check(server.code==404,"DEFECT UI light endpoint absent");
  reset();server.call("/api/settings",HTTP_POST,{{"homingTimeoutMs","99"},{"logRetentionRecords","100"}});check(server.code==200&&liftSettings.homingTimeoutMs==30000&&liftSettings.logRetentionRecords==2048,"DEFECT unsupported advertised setting fields silently ignored");
  reset();StoredLiftState x{};x.currentPosition=123456;StoredLiftState y{};check(store.save(x)&&store.load(y)&&y.currentPosition==123456,"position persistence round-trip in simulated Preferences");
  Preferences::data["lift/state"][12]^=1;check(!store.load(y),"position CRC rejects corrupted simulated blob");
  reset();Preferences::failWrites=true;servicePersistence();check(motionState==MotionState::Idle,"DEFECT periodic persistence failure not surfaced as fault");
  reset();for(int i=0;i<40;i++)eventLog.append(EventCode::Boot);String log=eventLog.jsonRecent();check(log.find("\"seq\":9,")!=String::npos && log.find("\"seq\":1,")==String::npos,"log retention is32 RAM events despite2048 setting");
  reset();fakePins[Pins::ButtonLeft]=HIGH;serviceButtons();check(motionState==MotionState::Moving,"DEFECT initial high button interpreted as new command");
  reset();std::strcpy(networkSettings.staSsid,"quote\"ssid");check(jsonNetworkStatus().find("quote\"ssid")!=String::npos,"DEFECT network SSID emitted without JSON escaping");
  reset();fakePins[Pins::UpperLimit]=LOW;fakePins[Pins::LowerLimit]=LOW;check(requestMoveToFloor(2),"DEFECT conflicting limits not rejected at command acceptance");
  reset();setPositionCounts(700);serviceMotion();check(motionState==MotionState::Idle,"DEFECT unexpected idle movement not detected");
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

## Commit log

2026-07-08 Initial elevator lift controller redesign
    [main.cpp]
2026-07-08 Add hardware matrix KiCad scaffold and VFD settings APIs
    [ElevatorLift.kicad_pcb, ElevatorLift.kicad_sch]
2026-07-09 Capture confirmed hardware constraints and KiCad 10 scaffold
    [ElevatorLift.kicad_pcb]
2026-07-09 Document measured stop calibration strategy
2026-09-05 Capture portable Rev-A hardware design
    [2770.step, ESP32-S3-WROOM-1U-N16R80.step, ESP32-S3-WROOM-1U-N16R81.step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]
2026-09-05 Add ESP32 lift controller webapp
2026-09-13 Add inhibited controller integration baseline
    [Configuration.h, partitions.csv]
2026-09-14 Finalize Rev-A PCB preparation
    [ElevatorLift.kicad_pcb, IO.kicad_sch, MCU_Storage_RevA.kicad_sch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]
